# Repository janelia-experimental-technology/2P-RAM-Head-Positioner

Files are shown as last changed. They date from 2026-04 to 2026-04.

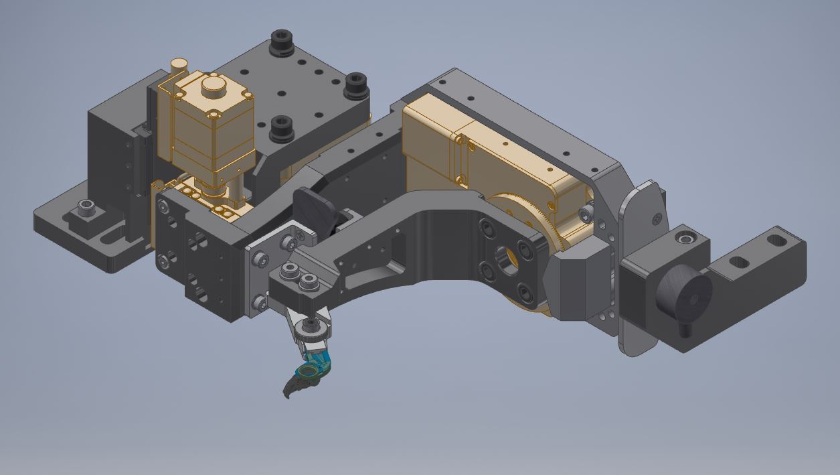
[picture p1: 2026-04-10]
V1-Original Design/MBS POSITIONER SCREENSHOT.JPG

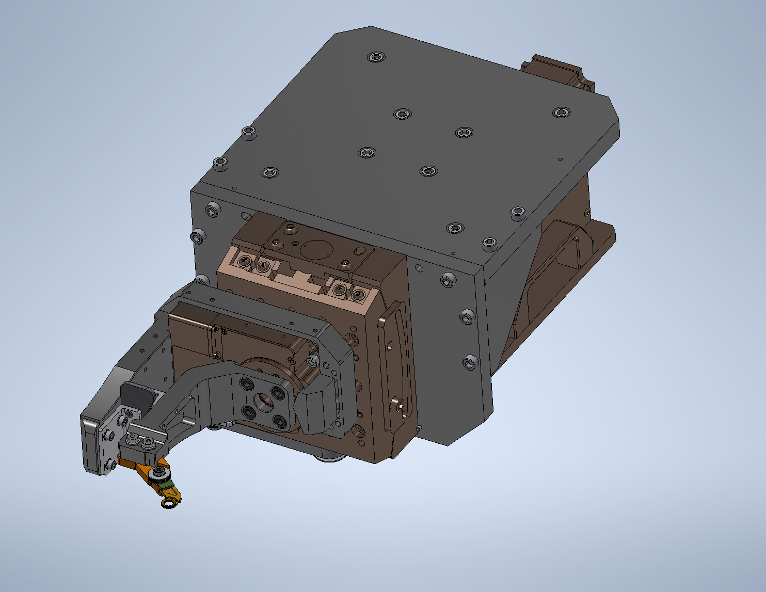
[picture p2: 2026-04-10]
V2-Revised Design/2P-RAM HEAD POSITIONER V2.png

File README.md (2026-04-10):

### Head Positioner for 2P-RAM 2P-RAM Imaging

The motorized head positioner/goniometer allows the user to position the headbar in an automated, repeatable location underneath the microscope. It was designed to work with the 2P-RAM microscope objective and headbars, and leaves the sides of the mouse’s head unobstructed so that camera lenses or other equipment may be mounted close to the head. The device provides automated rotation of a head-fixed rodent specimen about the anterior-posterior and medio-lateral axes for imaging or other purposes. The rotation center of the device is the center of the headbar window opening. The device also provides automated Z translation and is designed to be compatible with behavioral setups such as the large spherical and other treadmills. There are two designs contained herein. The first is designed using stages from Zaber only and is included for reference. The second design which we recommend uses a rotation stages from Zaber and two other stages from Optics Focus which provide a more stable platform. 

Specifications:

&#x20;   Rotation range around Anterior-Posterior axis : +/-20 degrees

&#x20;   Rotation range around Medio-Lateral axis : +/- 8 degrees

&#x20;   Z travel: +/- 10 mm

Opportunity: Free to make for Non-Profit Research by downloading the design here. See included hardware license.

Rights and designs available for Commercial License. Janelia makes no endorsements or guarantees of licensee products.

For inquiries, please contact innovation@janelia.hhmi.org and reference this repository.

To cite the designs, please use DOI: https://doi.org/10.25378/janelia.31985325

Supercedes FLintbox ID 2018-018.

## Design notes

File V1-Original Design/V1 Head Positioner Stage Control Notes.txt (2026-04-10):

The Motorized stages in the V1 Head Positioner design are controlled by Zaber stepper motor controllers. These in combination with the Zaber Console software allow easy control and positioning of the three axes. The V1 positioner has three Zaber stages which connect directly to the Zaber Controllers. The original Zaber A-MCA controllers are now obsolete and we recommend the X-MCC 3 axis controller as a suitable replacement.

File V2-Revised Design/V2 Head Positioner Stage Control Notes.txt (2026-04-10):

The Motorized stages in the V2 Head Positioner design are controlled by Zaber stepper motor controllers. These in combination with the Zaber Console software allow easy control and positioning of the three axes. The V2 positioner has one Zaber rotary stage and two stepper motor driven stages from Optics Focus ( the goniometer and Z stage). Adapter cables were made connecting the DB9 connectors on the Optics Focus stages to the Zaber Controllers. Pinout diagrams can be found on the Optics Focus and Zaber websites for reference. The original Zaber A-MCA controllers are now obsolete and we recommend the X-MCC 3 axis controller as a suitable replacement.

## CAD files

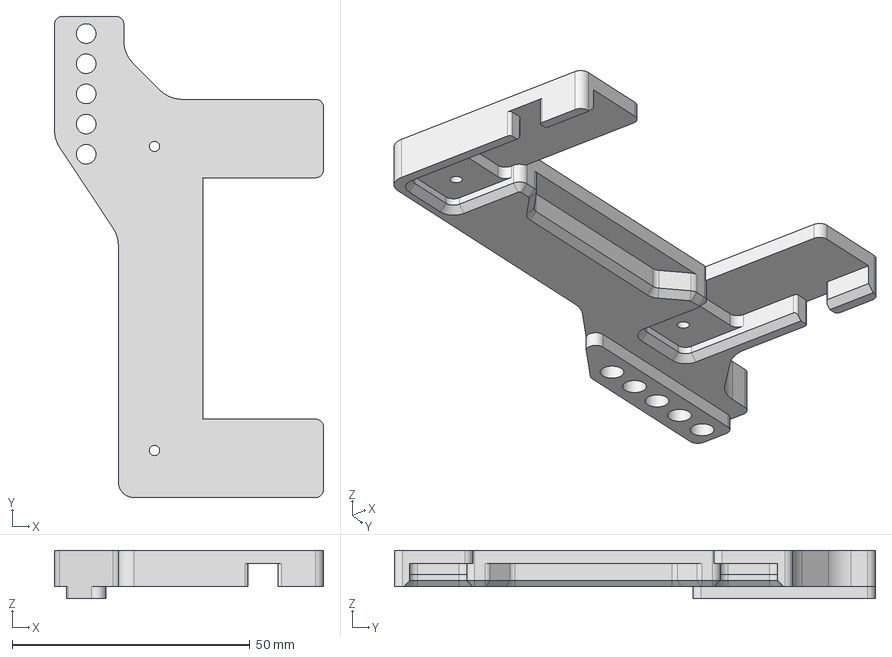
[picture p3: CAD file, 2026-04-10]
V1-Original Design/Part Drawings and Models/MBS INLINE SLIDE HOLDER Rev - J005316.stp
56.6 x 101.3 x 10.2 mm

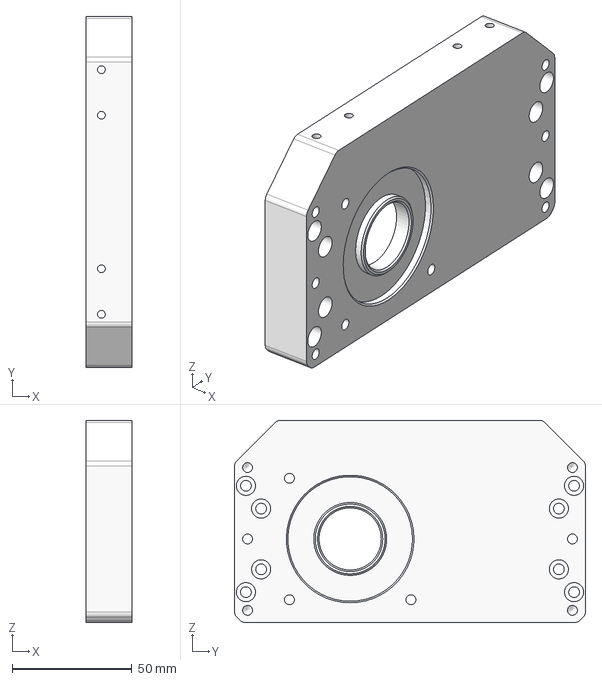
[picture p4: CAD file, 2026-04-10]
V1-Original Design/Part Drawings and Models/J003054 MBS OUTER POSARM L Rev -.stp
19.1 x 146.7 x 84.5 mm

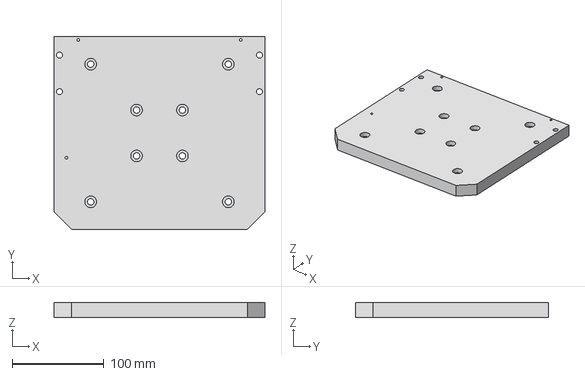
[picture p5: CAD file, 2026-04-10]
V2-Revised Design/Part Models and Drawings/J008085 BBP Z STAGE MTG PLATE Rev - .stp
230.0 x 210.0 x 15.9 mm

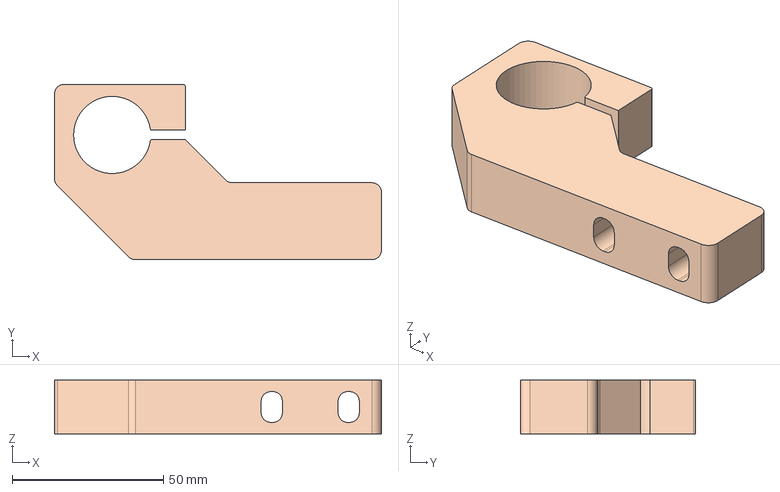
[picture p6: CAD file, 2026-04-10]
V1-Original Design/Part Drawings and Models/J005363 MBS MAGNET MOUNT Rev -.stp
107.9 x 57.9 x 17.8 mm

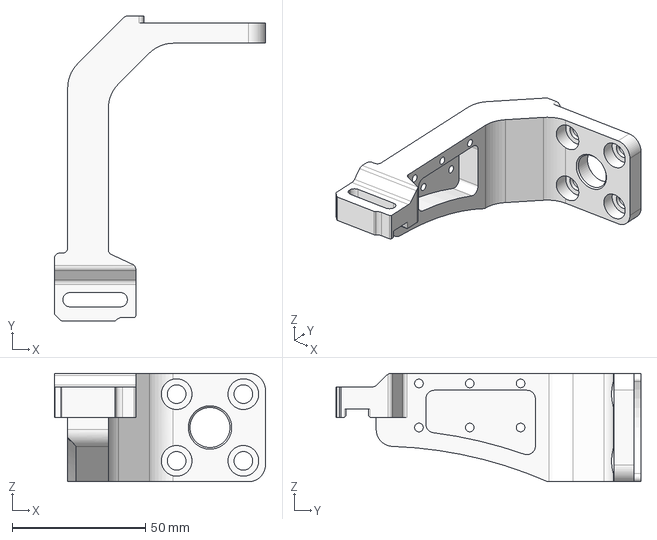
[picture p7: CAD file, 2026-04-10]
V2-Revised Design/Part Models and Drawings/J003057 MBS INNER POSARM Rev -.stp
79.1 x 114.2 x 40.6 mm

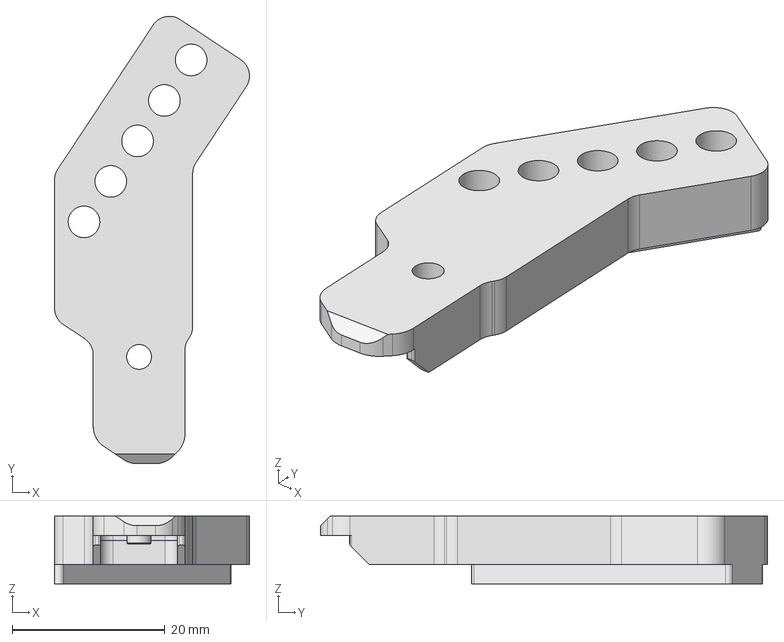
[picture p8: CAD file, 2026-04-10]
V1-Original Design/Part Drawings and Models/J005048 MBS Inline Clamp Arm Rev A.stp
25.5 x 58.5 x 8.89 mm

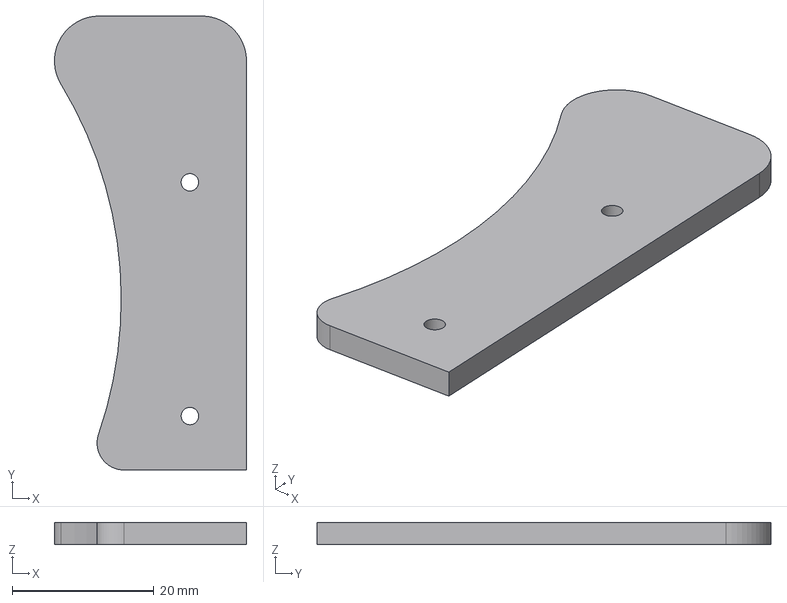
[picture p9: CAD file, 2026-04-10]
V2-Revised Design/Part Models and Drawings/J005357 MBS OUTER STLPART Rev -.stp
27.1 x 64.1 x 3.17 mm

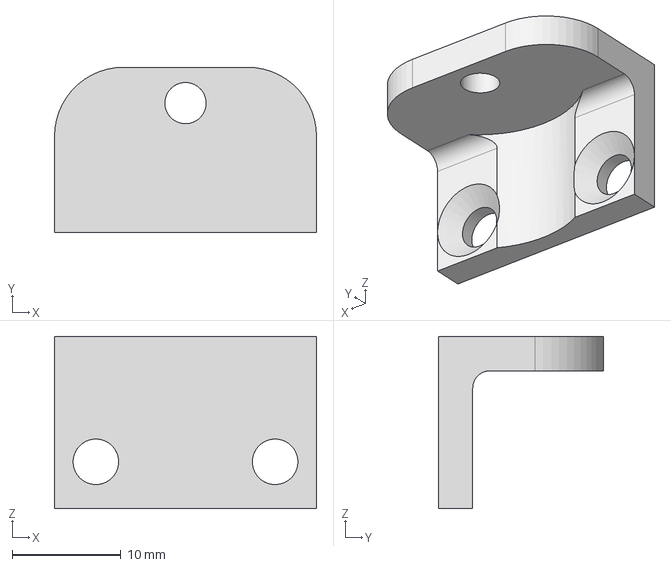
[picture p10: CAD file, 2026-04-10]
V1-Original Design/Part Drawings and Models/J005359 MBS 0_75 EM MNT CLOSER Rev -.stp
24.1 x 15.2 x 15.9 mm

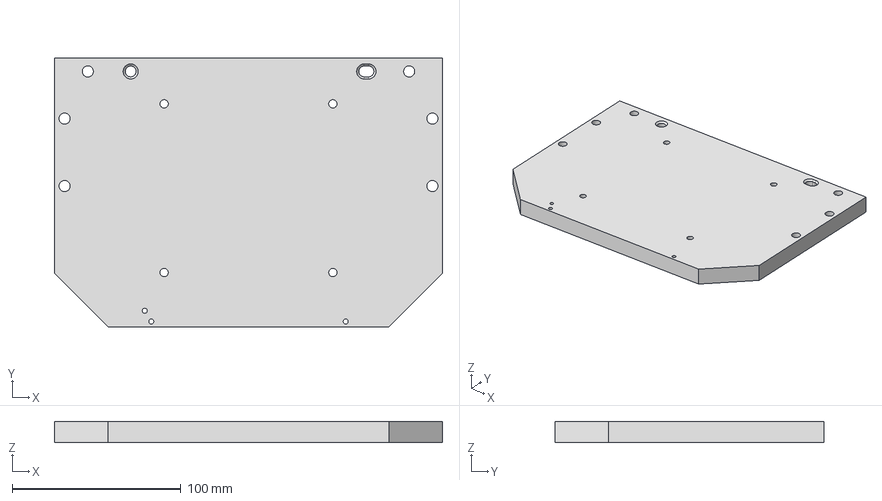
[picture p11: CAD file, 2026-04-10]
V2-Revised Design/Part Models and Drawings/J008086 BBP G STAGE MTG PLATE Rev - .stp
230.0 x 159.4 x 12.7 mm

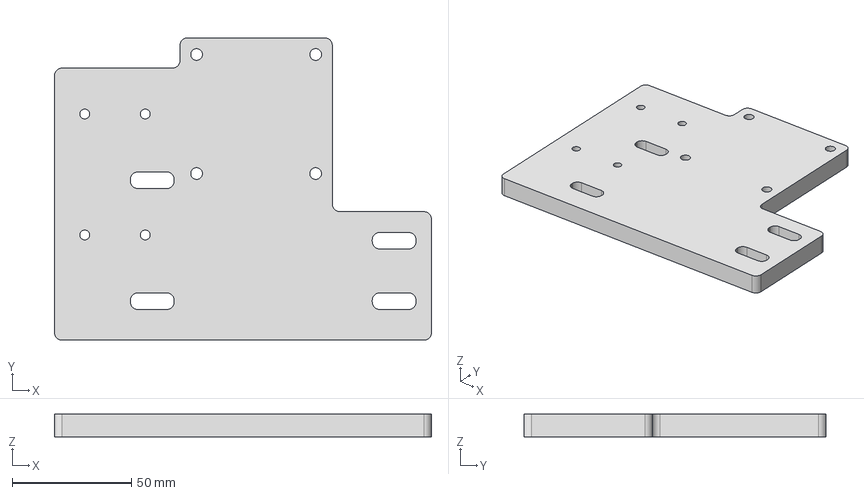
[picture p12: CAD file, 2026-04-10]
V1-Original Design/Part Drawings and Models/J005167 MBS POSITIONER BASE PLATE Rev -.stp
158.4 x 127.0 x 9.53 mm

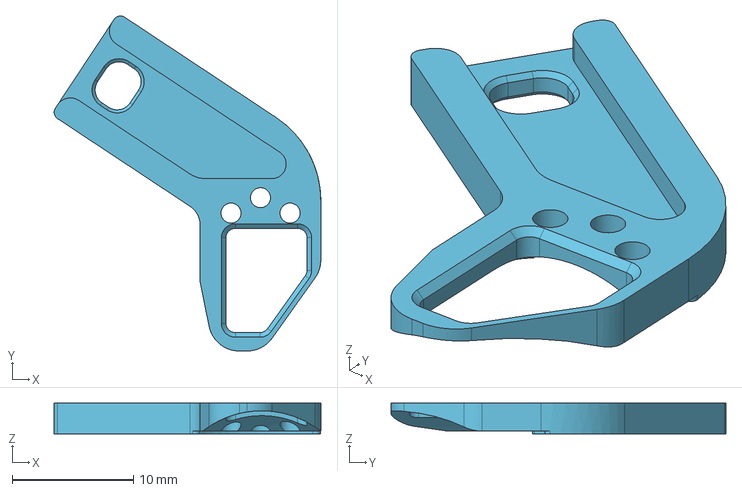
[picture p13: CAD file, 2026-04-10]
V1-Original Design/Part Drawings and Models/J005483 MBS INLINE D TAB Rev A.stp
22.0 x 27.6 x 2.54 mm

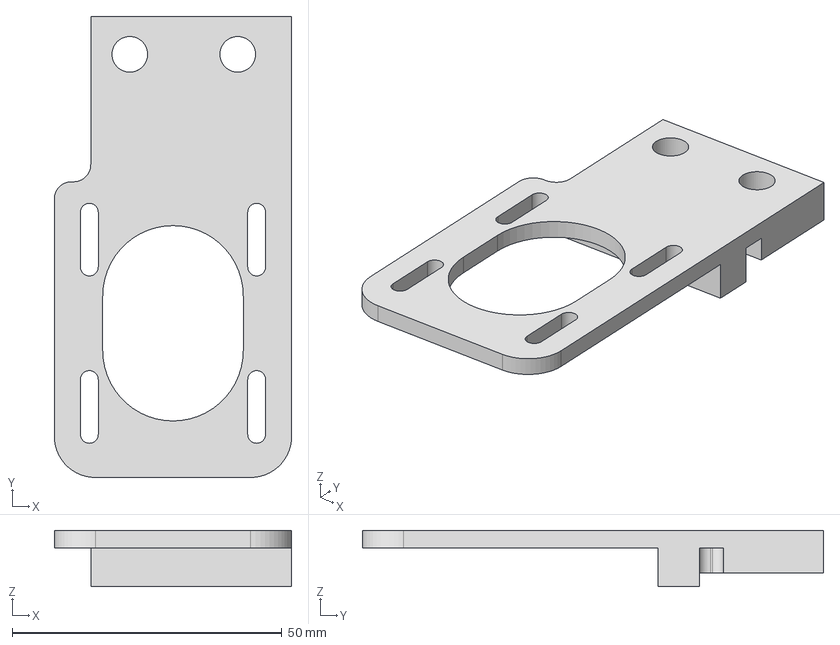
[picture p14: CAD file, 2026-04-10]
V2-Revised Design/Part Models and Drawings/J008087 BBP GONIO MOTOR SHIFT PLATE Rev -.stp
44.0 x 85.4 x 10.4 mm

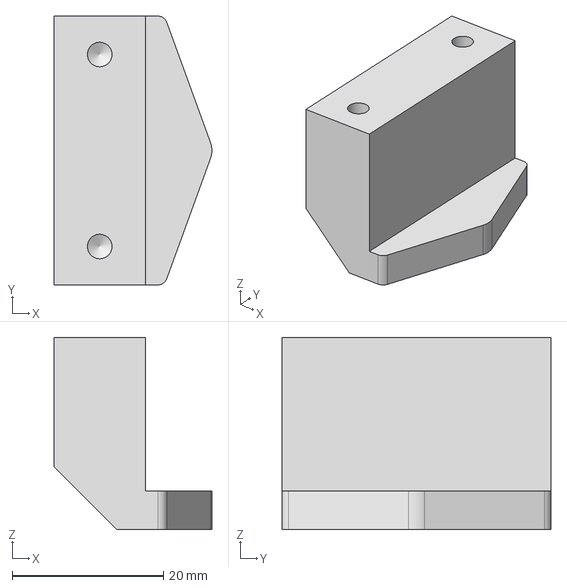
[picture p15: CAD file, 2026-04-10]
V1-Original Design/Part Drawings and Models/J005413 MBS HARD STOP BASE Rev - .stp
20.9 x 35.6 x 25.4 mm

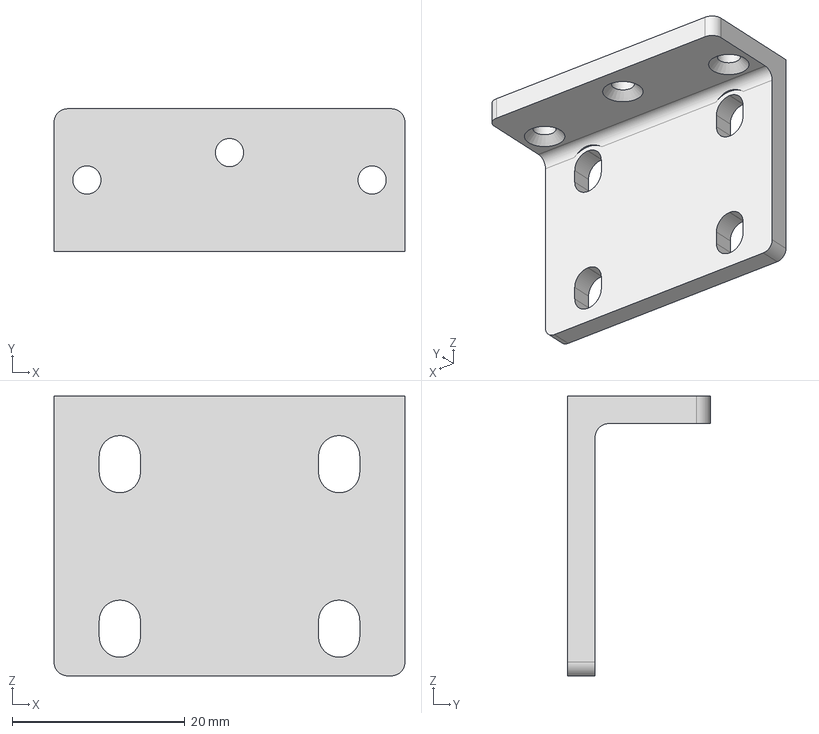
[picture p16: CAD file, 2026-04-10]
V2-Revised Design/Part Models and Drawings/J005358 MBS OUTER PA GUIDE ANGLE Rev -.stp
40.6 x 16.5 x 32.4 mm

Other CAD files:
V1-Original Design/Part Drawings and Models/J005362 MBS LOCK MTG BRACKET Rev -.stp
V2-Revised Design/Part Models and Drawings/J008101 BBP OUTER POSARM L Rev -.stp
V1-Original Design/Inventor Pack and Go/10572.ipt
V1-Original Design/Inventor Pack and Go/5698K113.ipt
V1-Original Design/Inventor Pack and Go/90145A512.ipt
V1-Original Design/Inventor Pack and Go/90666A124.ipt
V1-Original Design/Inventor Pack and Go/90945A726.ipt
V1-Original Design/Inventor Pack and Go/90965A130.ipt
V1-Original Design/Inventor Pack and Go/90965A170.ipt
V1-Original Design/Inventor Pack and Go/91111A118.ipt
V1-Original Design/Inventor Pack and Go/91290A073.ipt
V1-Original Design/Inventor Pack and Go/91292A112.ipt
V1-Original Design/Inventor Pack and Go/91292A116.ipt
V1-Original Design/Inventor Pack and Go/91292A121.ipt
V1-Original Design/Inventor Pack and Go/91292A126.ipt
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

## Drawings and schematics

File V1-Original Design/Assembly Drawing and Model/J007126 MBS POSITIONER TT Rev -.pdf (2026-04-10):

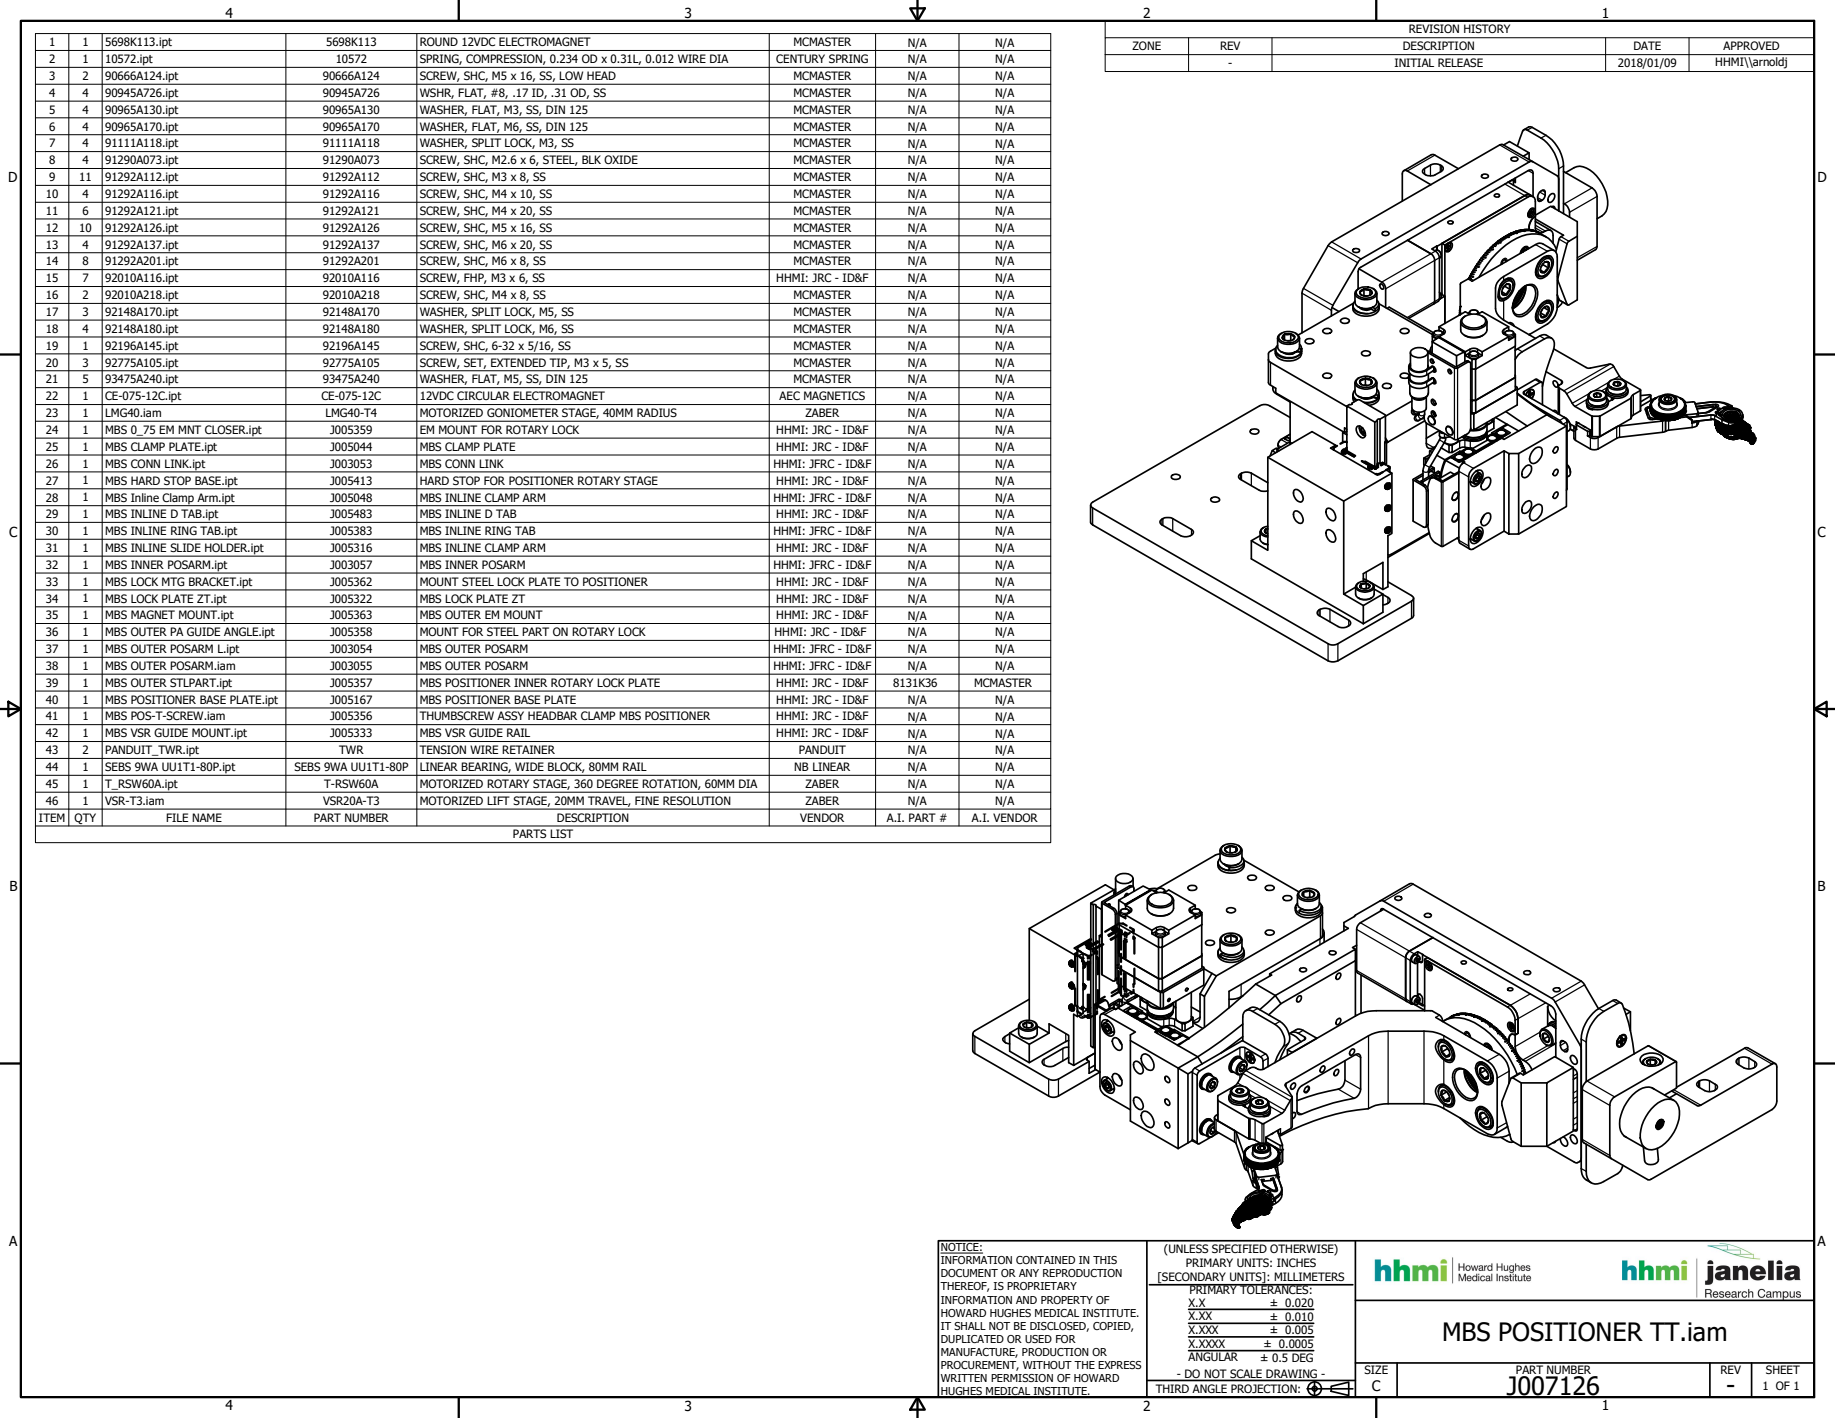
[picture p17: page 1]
5698K113.ipt; ROUND 12VDC ELECTROMAGNET; MCMASTER; 10572.ipt; SPRING, COMPRESSION, 0.234 OD x 0.31L, 0.012 WIRE DIA; CENTURY SPRING; 90666A124.ipt; SCREW, SHC, M5 x 16, SS, LOW HEAD; 90945A726.ipt; WSHR, FLAT, #8, .17 ID, .31 OD, SS; 90965A130.ipt; WASHER, FLAT, M3, SS, DIN 125; 90965A170.ipt; WASHER, FLAT, M6, SS, DIN 125; 91111A118.ipt; WASHER, SPLIT LOCK, M3, SS; 91290A073.ipt; SCREW, SHC, M2.6 x 6, STEEL, BLK OXIDE; 11 91292A112.ipt; SCREW, SHC, M3 x 8, SS; 91292A116.ipt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

NOTICE:
INFORMATION CONTAINED IN THIS
DOCUMENT OR ANY REPRODUCTION
THEREOF, IS PROPRIETARY
INFORMATION AND PROPERTY OF
HOWARD HUGHES MEDICAL INSTITUTE.
IT SHALL NOT BE DISCLOSED, COPIED,
DUPLICATED OR USED FOR
MANUFACTURE, PRODUCTION OR
PROCUREMENT, WITHOUT THE EXPRESS
WRITTEN PERMISSION OF HOWARD
HUGHES MEDICAL INSTITUTE.

(UNLESS SPECIFIED OTHERWISE)
PRIMARY UNITS: INCHES
[SECONDARY UNITS]: MILLIMETERS
PRIMARY TOLERANCES:
X.XXX
X.XXXX
ANGULAR
- DO NOT SCALE DRAWING -

MBS POSITIONER TT.iam

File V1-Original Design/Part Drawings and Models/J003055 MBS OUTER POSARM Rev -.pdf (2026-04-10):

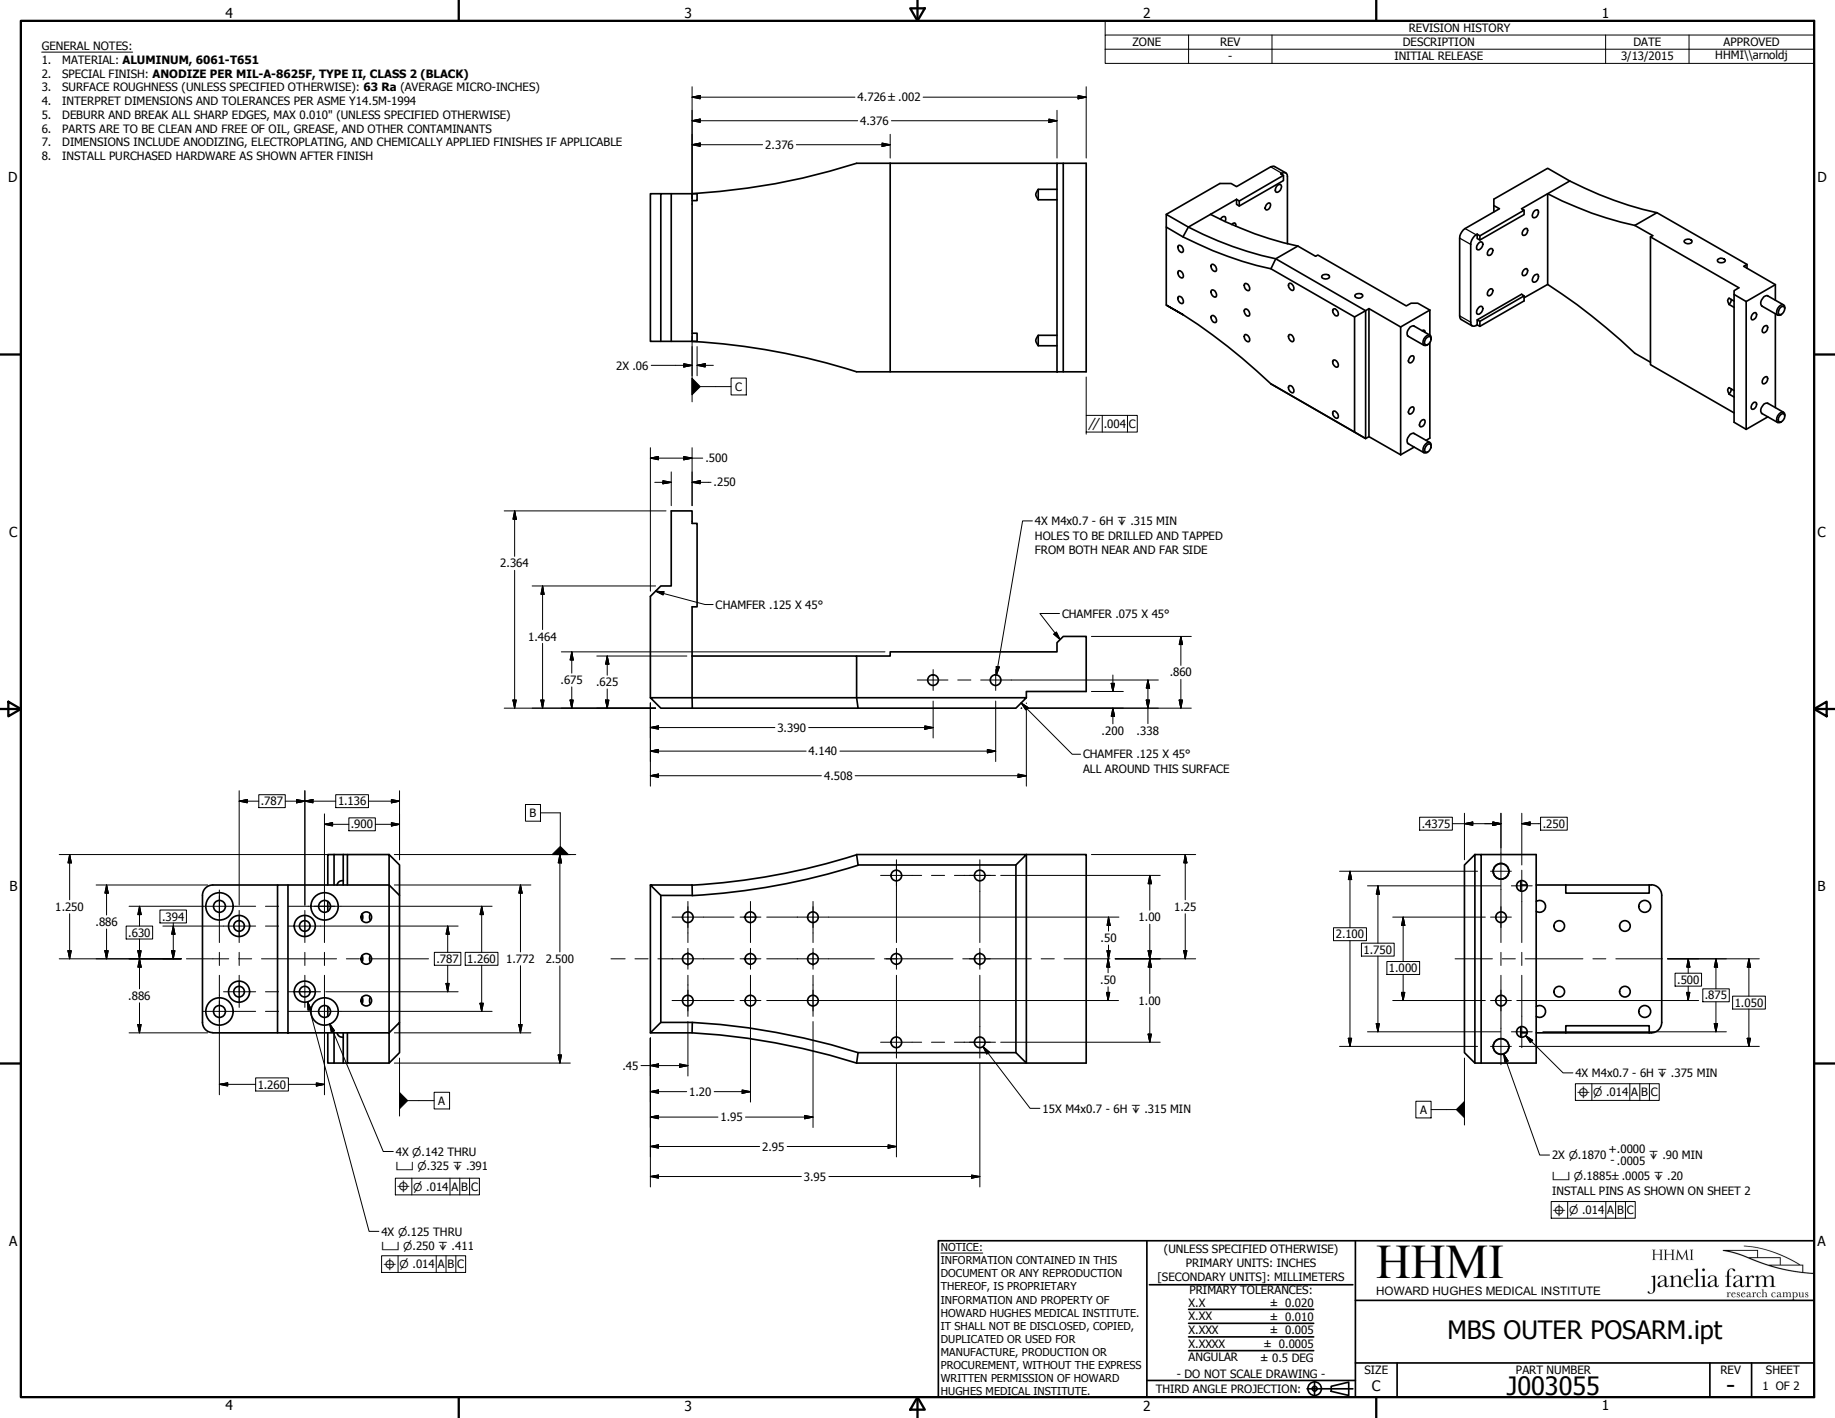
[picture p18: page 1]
PART NUMBER; HHMI; SIZE; REV; SHEET; 1 OF 2 THIRD ANGLE PROJECTION:; ± 0.020 ± 0.010 ± 0.005 ± 0.0005 ± 0.5 DEG; REVISION HISTORY; ZONE; DESCRIPTION; DATE; APPROVED; INITIAL RELEASE; HHMI\\arnoldj; CHAMFER .125 X 45°; 15X M4x0.7 - 6H Z .315 MIN; +.0000 Z .90 MIN; 4X M4x0.7 - 6H Z .375 MIN; CHAMFER .075 X 45°; 4X P.142 THRU X P.325 Z .391; 4X P.125 THRU X P.250 Z .411

GENERAL NOTES:
1. MATERIAL: ALUMINUM, 6061-T651
2. SPECIAL FINISH: ANODIZE PER MIL-A-8625F, TYPE II, CLASS 2 (BLACK)
3. SURFACE ROUGHNESS (UNLESS SPECIFIED OTHERWISE): 63 Ra (AVERAGE MICRO-INCHES)
4. INTERPRET DIMENSIONS AND TOLERANCES PER ASME Y14.5M-1994
5. DEBURR AND BREAK ALL SHARP EDGES, MAX 0.010" (UNLESS SPECIFIED OTHERWISE)
6. PARTS ARE TO BE CLEAN AND FREE OF OIL, GREASE, AND OTHER CONTAMINANTS
7. DIMENSIONS INCLUDE ANODIZING, ELECTROPLATING, AND CHEMICALLY APPLIED FINISHES IF APPLICABLE
8. INSTALL PURCHASED HARDWARE AS SHOWN AFTER FINISH

4X M4x0.7 - 6H Z .315 MIN
HOLES TO BE DRILLED AND TAPPED
FROM BOTH NEAR AND FAR SIDE

CHAMFER .125 X 45°
ALL AROUND THIS SURFACE

INSTALL PINS AS SHOWN ON SHEET 2

NOTICE:
INFORMATION CONTAINED IN THIS
DOCUMENT OR ANY REPRODUCTION
THEREOF, IS PROPRIETARY
INFORMATION AND PROPERTY OF
HOWARD HUGHES MEDICAL INSTITUTE.
IT SHALL NOT BE DISCLOSED, COPIED,
DUPLICATED OR USED FOR
MANUFACTURE, PRODUCTION OR
PROCUREMENT, WITHOUT THE EXPRESS
WRITTEN PERMISSION OF HOWARD
HUGHES MEDICAL INSTITUTE.

(UNLESS SPECIFIED OTHERWISE)
PRIMARY UNITS: INCHES
[SECONDARY UNITS]: MILLIMETERS
PRIMARY TOLERANCES:
X.XXX
X.XXXX
ANGULAR
- DO NOT SCALE DRAWING -

HOWARD HUGHES MEDICAL INSTITUTE
MBS OUTER POSARM.ipt

# SECTION E-E

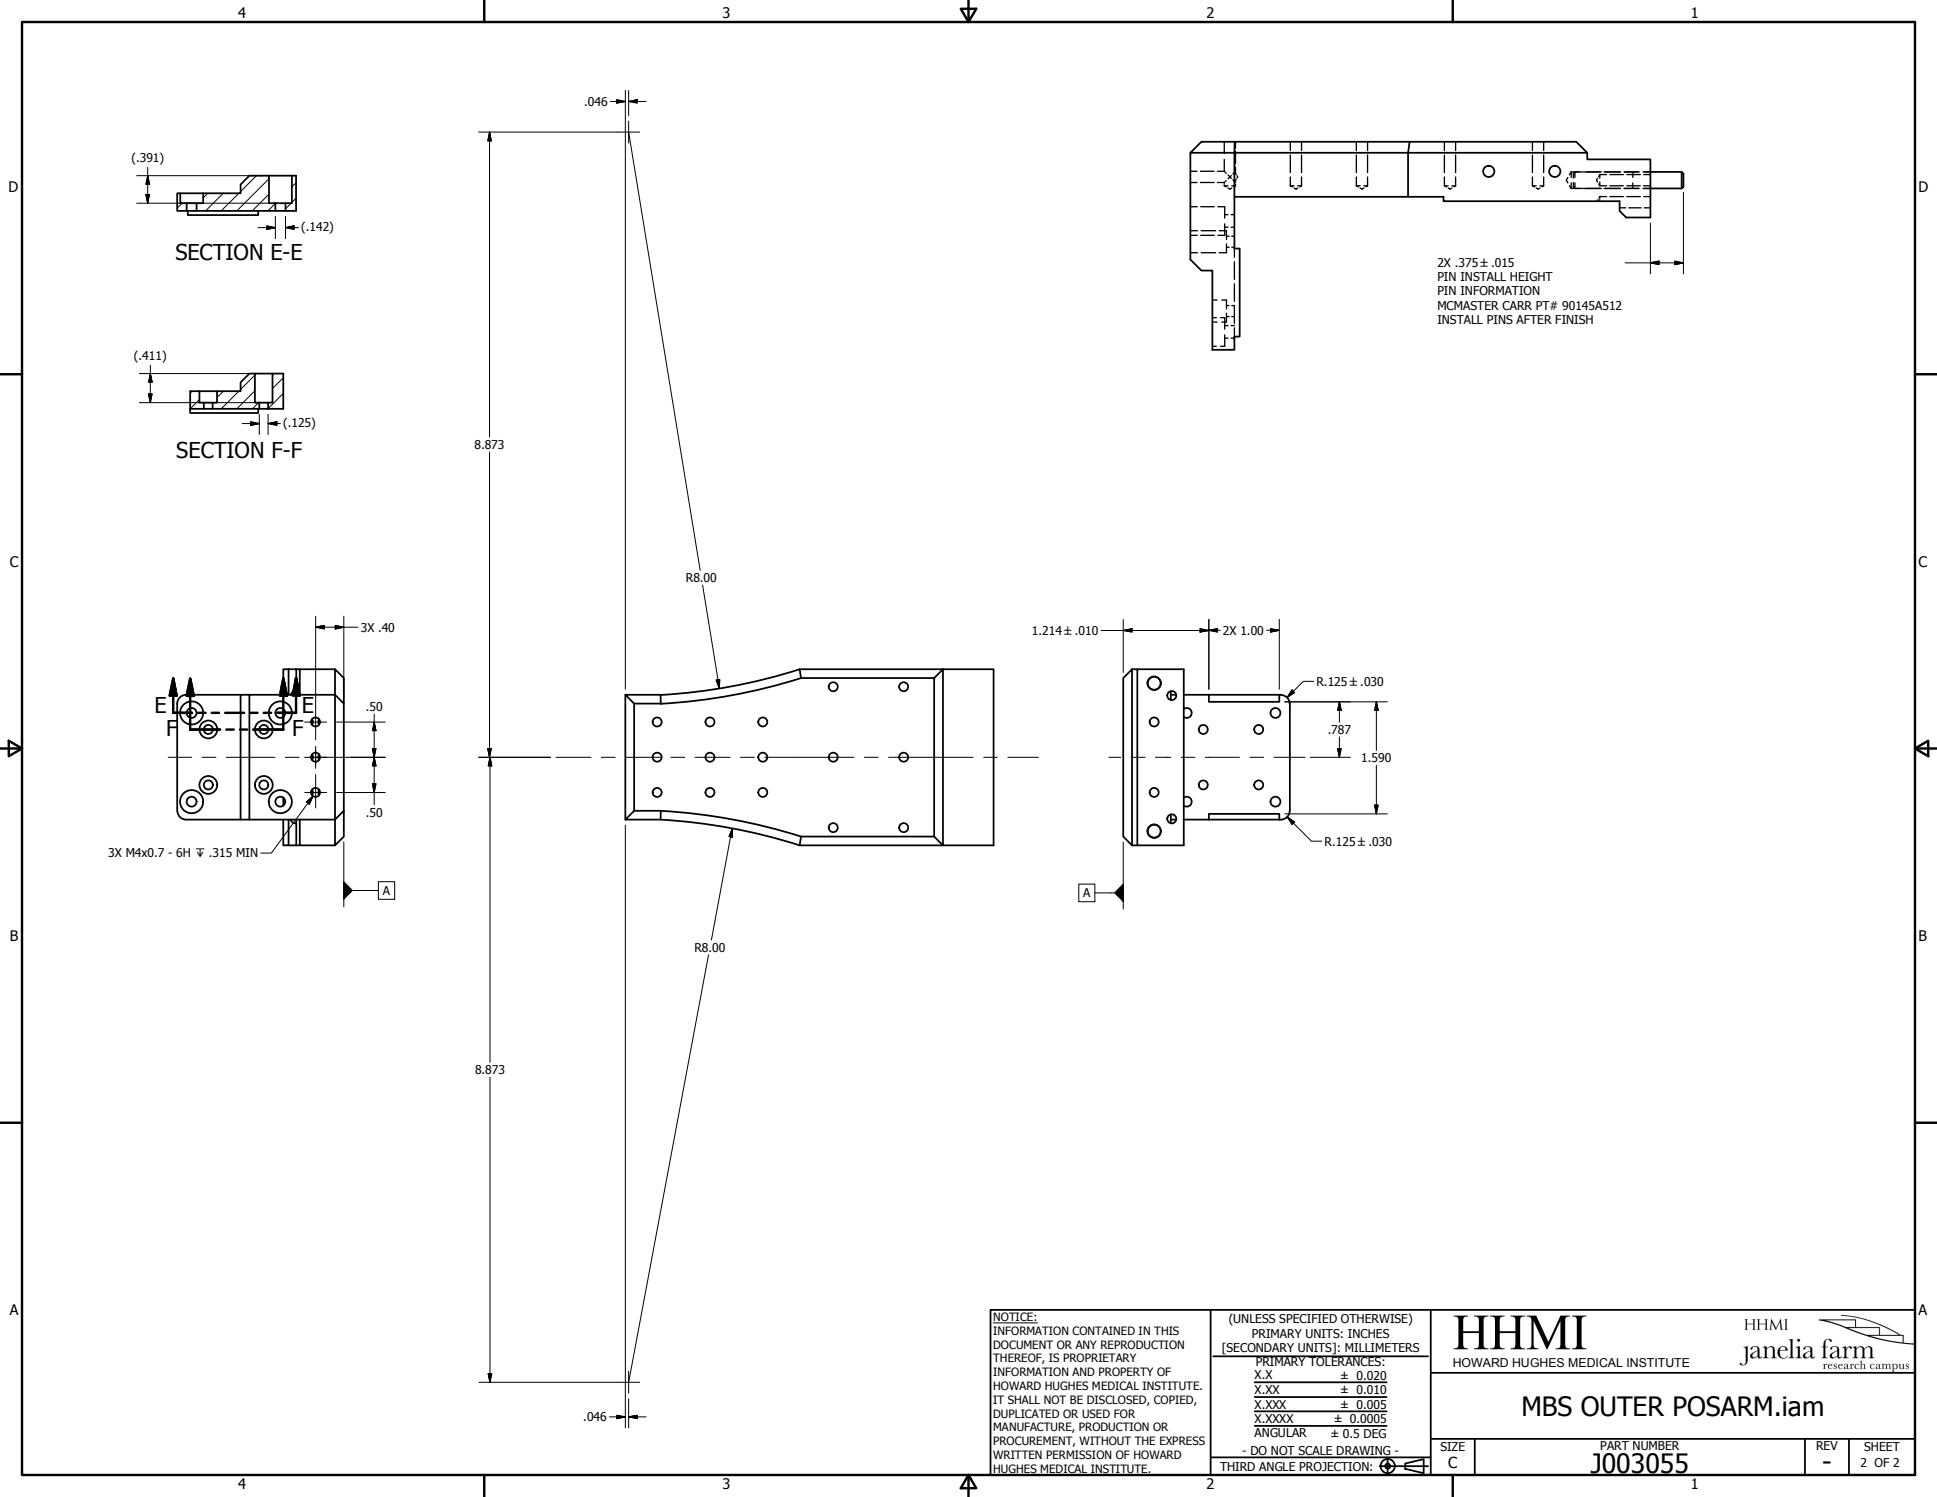
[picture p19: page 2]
SECTION F-F; PART NUMBER; HHMI; SIZE; REV; SHEET; 2 OF 2 THIRD ANGLE PROJECTION:; ± 0.020 ± 0.010 ± 0.005 ± 0.0005 ± 0.5 DEG; 3X M4x0.7 - 6H Z .315 MIN

PIN INSTALL HEIGHT
PIN INFORMATION
MCMASTER CARR PT# 90145A512
INSTALL PINS AFTER FINISH

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

HOWARD HUGHES MEDICAL INSTITUTE
MBS OUTER POSARM.iam

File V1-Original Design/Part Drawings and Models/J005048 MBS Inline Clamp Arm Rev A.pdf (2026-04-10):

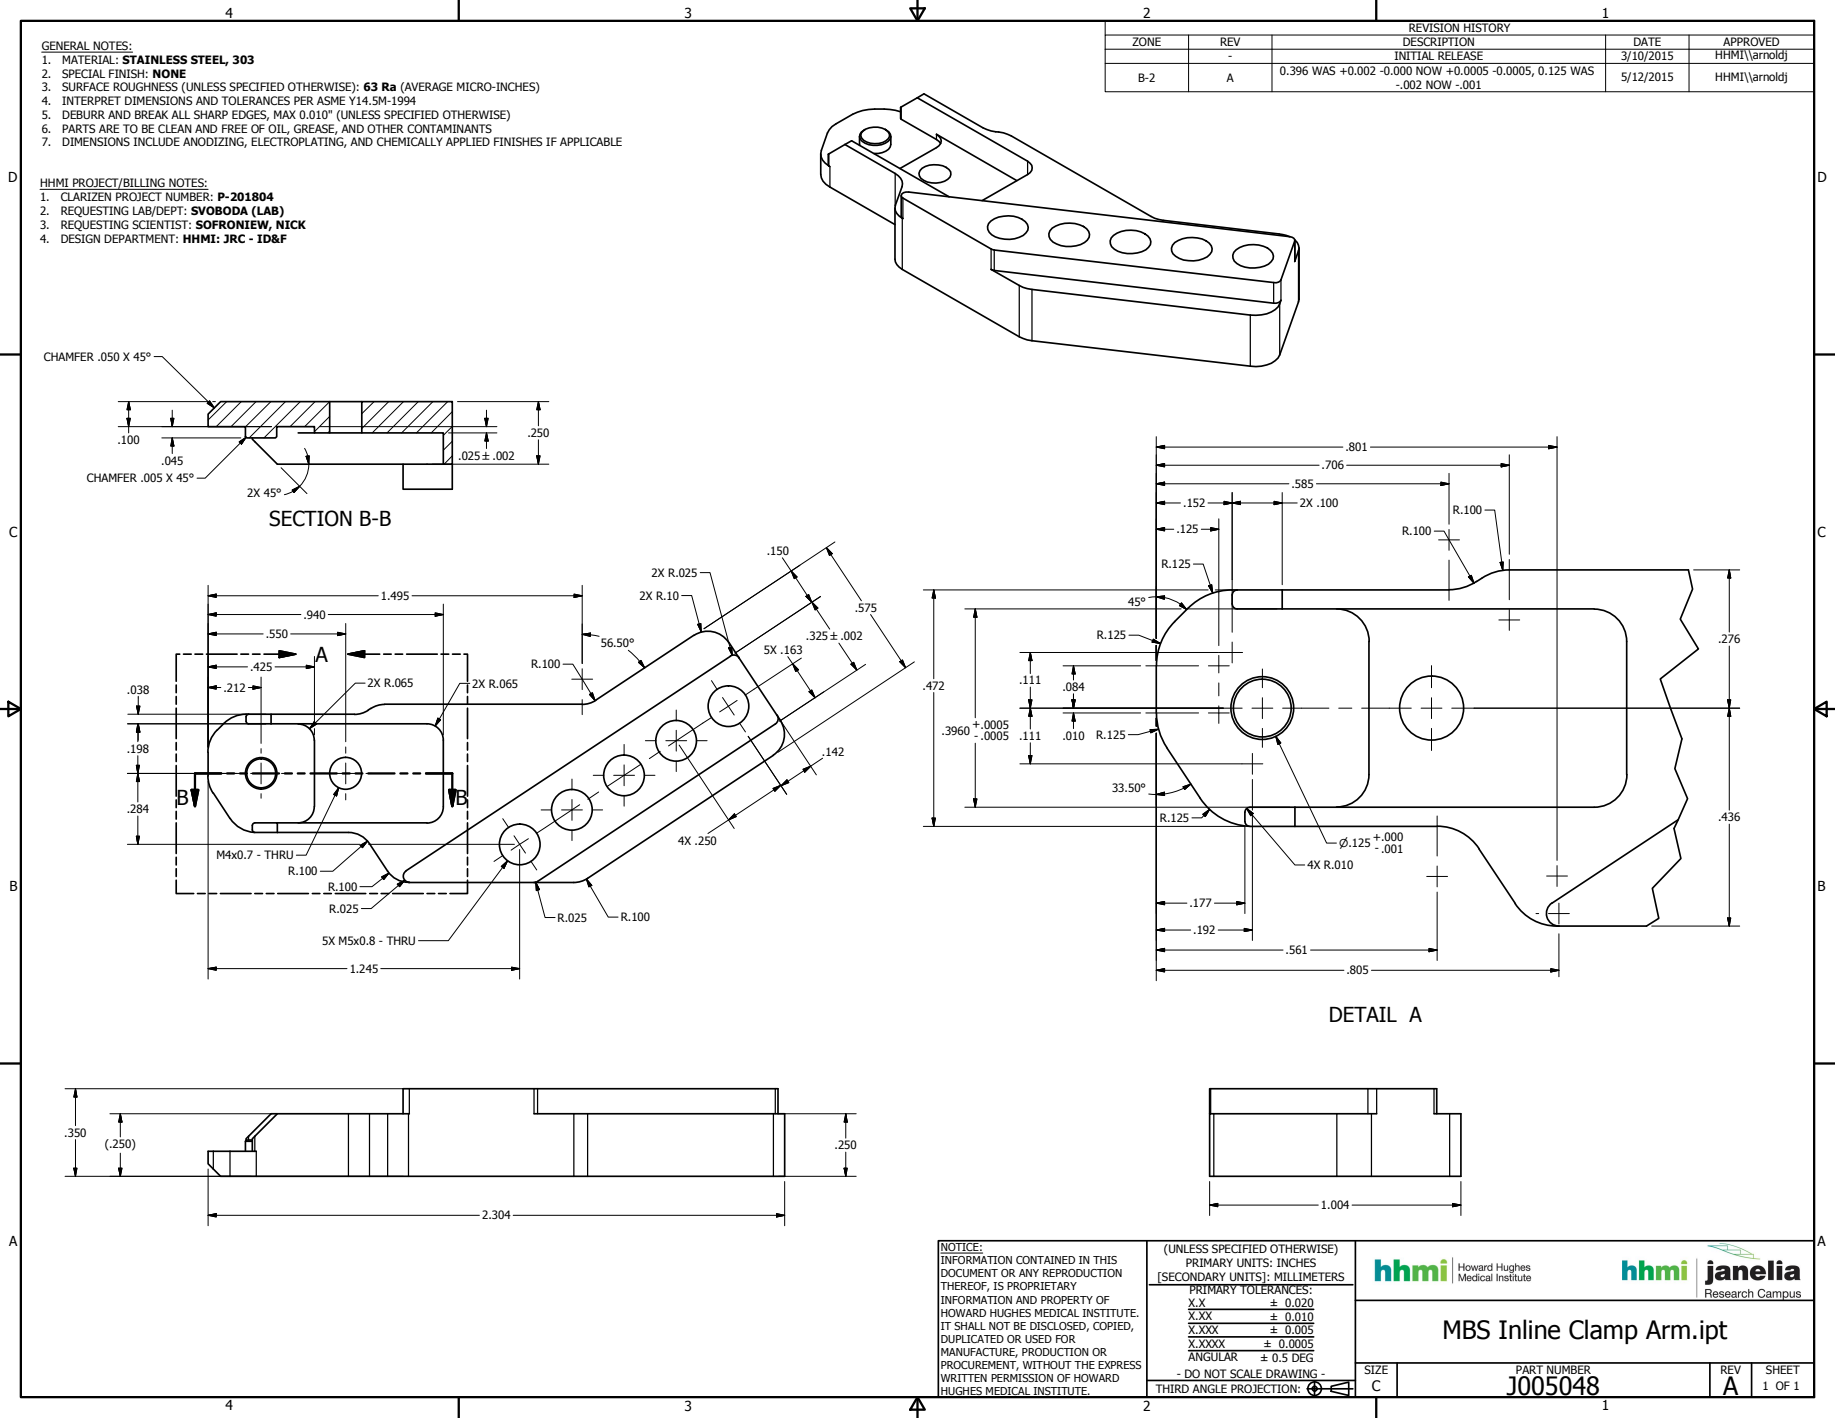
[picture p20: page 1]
DETAIL A; SECTION B-B; PART NUMBER; SIZE; REV; SHEET; 1 OF 1 THIRD ANGLE PROJECTION:; ± 0.020 ± 0.010 ± 0.005 ± 0.0005 ± 0.5 DEG; REVISION HISTORY; ZONE; DESCRIPTION; DATE; APPROVED; INITIAL RELEASE; HHMI\\arnoldj; -.002 NOW -.001; CHAMFER .050 X 45°; CHAMFER .005 X 45°; M4x0.7 - THRU; 5X M5x0.8 - THRU

GENERAL NOTES:
1. MATERIAL: STAINLESS STEEL, 303
2. SPECIAL FINISH: NONE
3. SURFACE ROUGHNESS (UNLESS SPECIFIED OTHERWISE): 63 Ra (AVERAGE MICRO-INCHES)
4. INTERPRET DIMENSIONS AND TOLERANCES PER ASME Y14.5M-1994
5. DEBURR AND BREAK ALL SHARP EDGES, MAX 0.010" (UNLESS SPECIFIED OTHERWISE)
6. PARTS ARE TO BE CLEAN AND FREE OF OIL, GREASE, AND OTHER CONTAMINANTS
7. DIMENSIONS INCLUDE ANODIZING, ELECTROPLATING, AND CHEMICALLY APPLIED FINISHES IF APPLICABLE

0.396 WAS +0.002 -0.000 NOW +0.0005 -0.0005, 0.125 WAS

HHMI PROJECT/BILLING NOTES:
1. CLARIZEN PROJECT NUMBER: P-201804
2. REQUESTING LAB/DEPT: SVOBODA (LAB)
3. REQUESTING SCIENTIST: SOFRONIEW, NICK
4. DESIGN DEPARTMENT: HHMI: JRC - ID&F

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

MBS Inline Clamp Arm.ipt

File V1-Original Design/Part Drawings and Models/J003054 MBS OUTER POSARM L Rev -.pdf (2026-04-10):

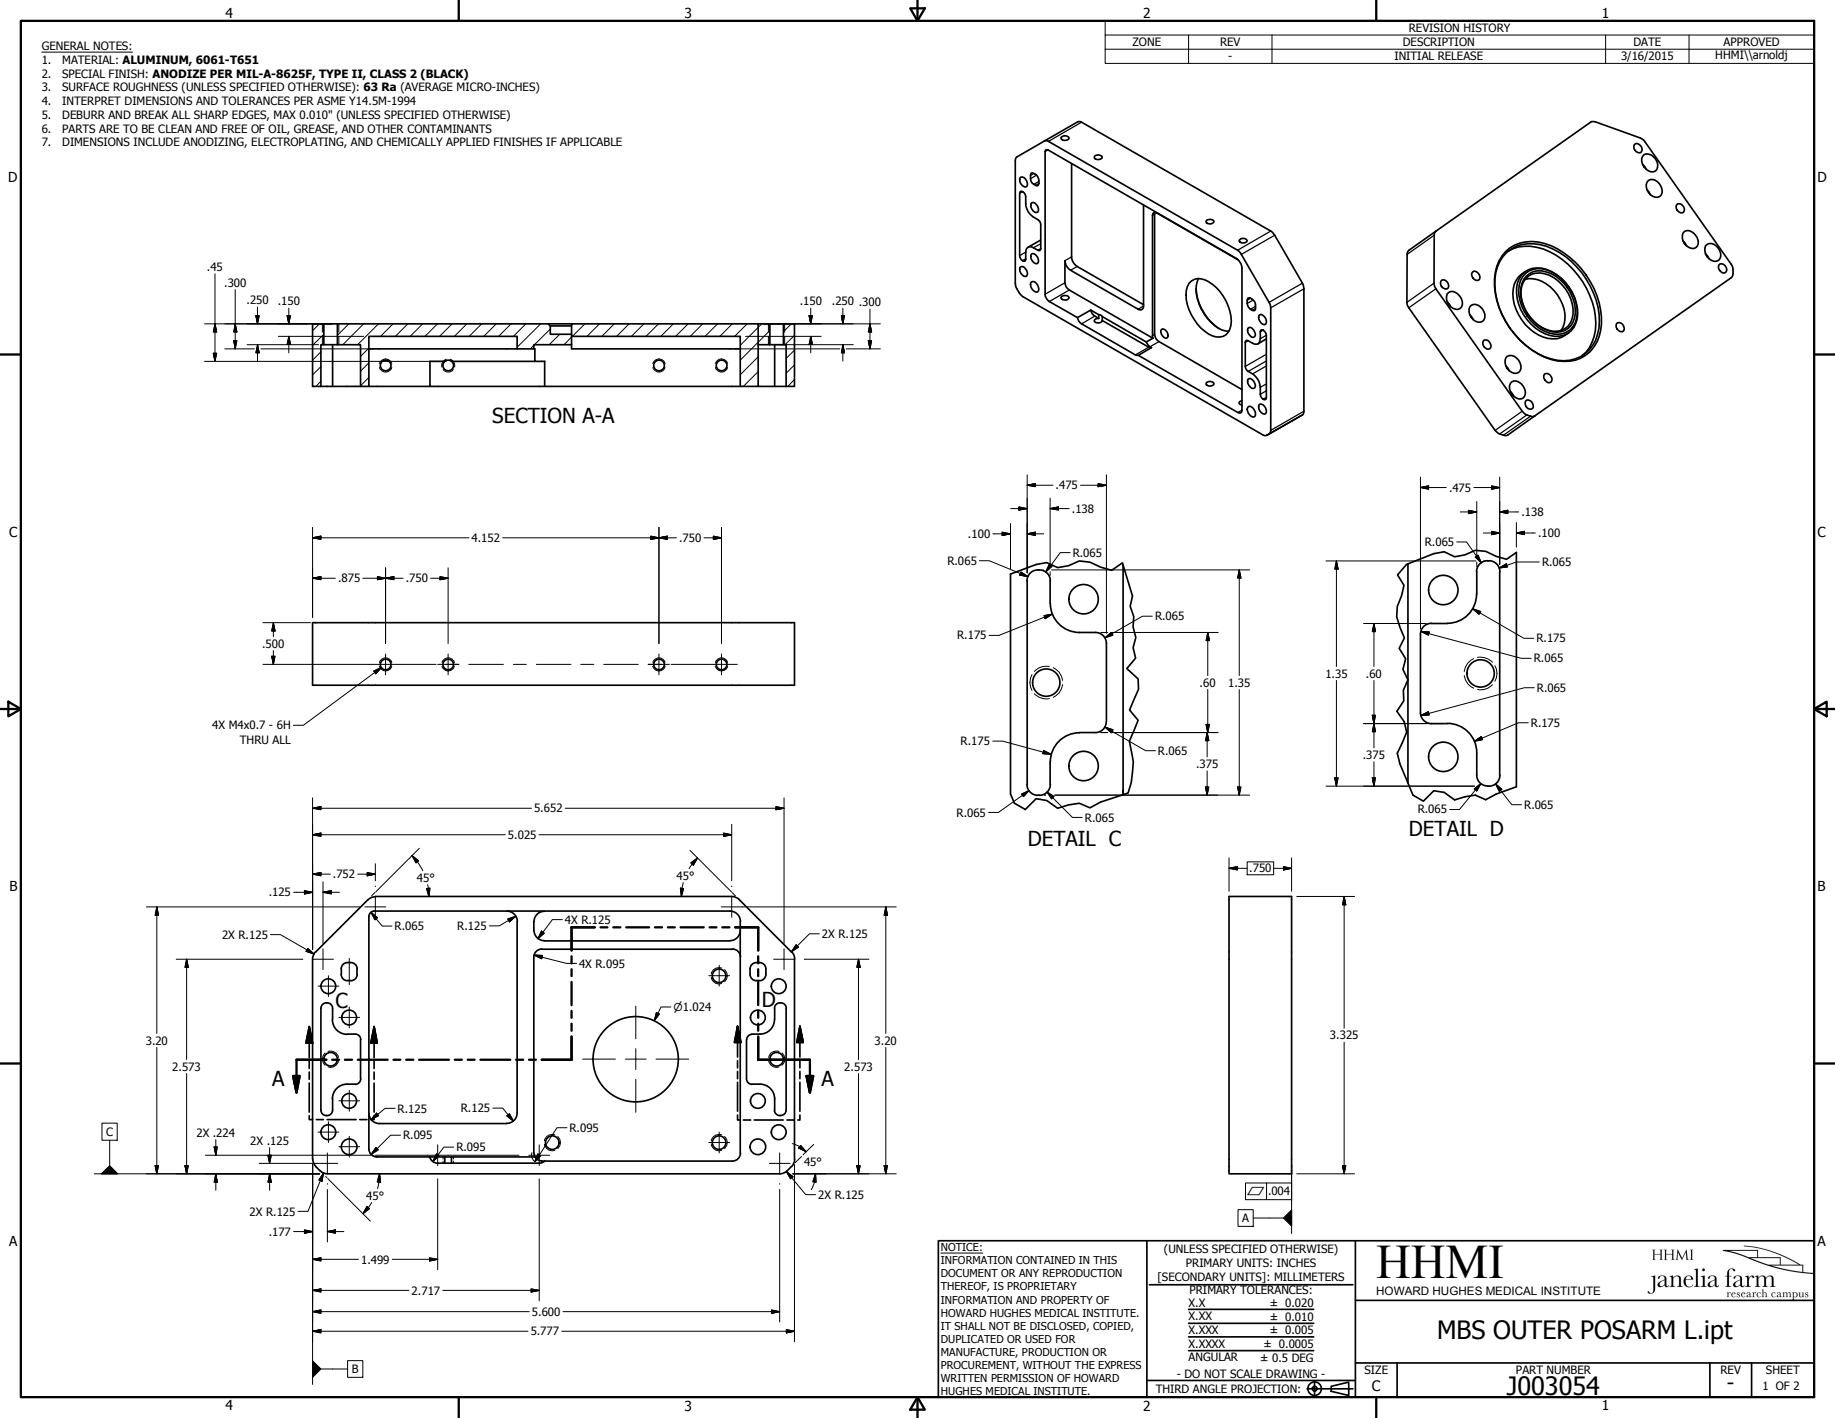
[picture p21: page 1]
SECTION A-A; DETAIL C; DETAIL D; PART NUMBER; HHMI; SIZE; REV; SHEET; 1 OF 2 THIRD ANGLE PROJECTION:; ± 0.020 ± 0.010 ± 0.005 ± 0.0005 ± 0.5 DEG; REVISION HISTORY; ZONE; DESCRIPTION; DATE; APPROVED; INITIAL RELEASE; HHMI\\arnoldj; 4X M4x0.7 - 6H THRU ALL

GENERAL NOTES:
1. MATERIAL: ALUMINUM, 6061-T651
2. SPECIAL FINISH: ANODIZE PER MIL-A-8625F, TYPE II, CLASS 2 (BLACK)
3. SURFACE ROUGHNESS (UNLESS SPECIFIED OTHERWISE): 63 Ra (AVERAGE MICRO-INCHES)
4. INTERPRET DIMENSIONS AND TOLERANCES PER ASME Y14.5M-1994
5. DEBURR AND BREAK ALL SHARP EDGES, MAX 0.010" (UNLESS SPECIFIED OTHERWISE)
6. PARTS ARE TO BE CLEAN AND FREE OF OIL, GREASE, AND OTHER CONTAMINANTS
7. DIMENSIONS INCLUDE ANODIZING, ELECTROPLATING, AND CHEMICALLY APPLIED FINISHES IF APPLICABLE

NOTICE:
INFORMATION CONTAINED IN THIS
DOCUMENT OR ANY REPRODUCTION
THEREOF, IS PROPRIETARY
INFORMATION AND PROPERTY OF
HOWARD HUGHES MEDICAL INSTITUTE.
IT SHALL NOT BE DISCLOSED, COPIED,
DUPLICATED OR USED FOR
MANUFACTURE, PRODUCTION OR
PROCUREMENT, WITHOUT THE EXPRESS
WRITTEN PERMISSION OF HOWARD
HUGHES MEDICAL INSTITUTE.

(UNLESS SPECIFIED OTHERWISE)
PRIMARY UNITS: INCHES
[SECONDARY UNITS]: MILLIMETERS
PRIMARY TOLERANCES:
X.XXX
X.XXXX
ANGULAR
- DO NOT SCALE DRAWING -

HOWARD HUGHES MEDICAL INSTITUTE
MBS OUTER POSARM L.ipt

E

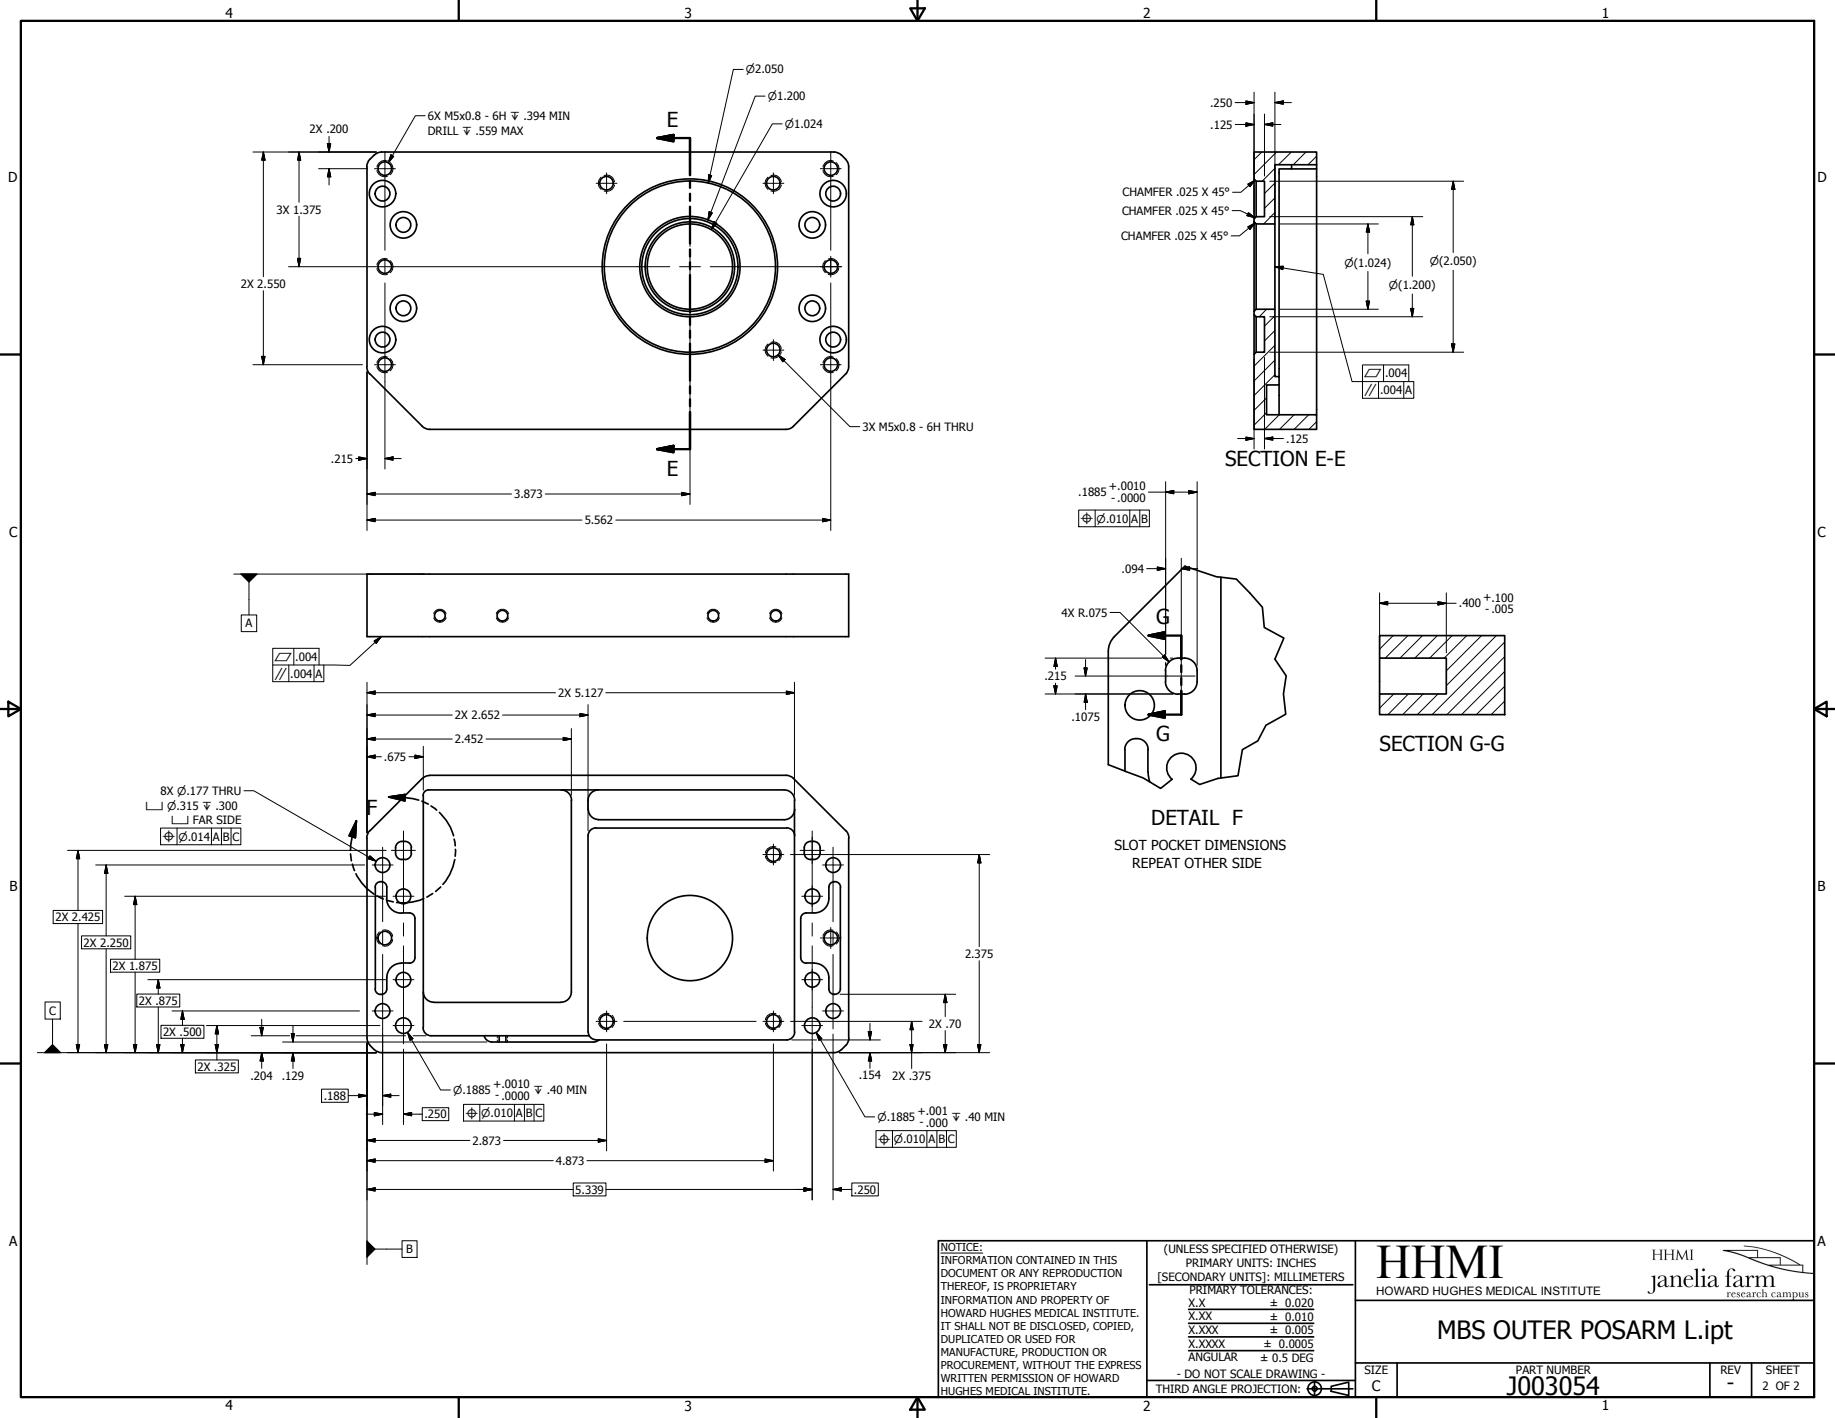
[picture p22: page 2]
SECTION E-E; DETAIL F; SECTION G-G; PART NUMBER; HHMI; SIZE; REV; SHEET; 2 OF 2 THIRD ANGLE PROJECTION:; ± 0.020 ± 0.010 ± 0.005 ± 0.0005 ± 0.5 DEG; CHAMFER .025 X 45°; 6X M5x0.8 - 6H Z .394 MIN DRILL Z .559 MAX; 8X P.177 THRU X P.315 Z .300 X FAR SIDE; +.0010 Z .40 MIN; +.001 Z .40 MIN; 3X M5x0.8 - 6H THRU

SLOT POCKET DIMENSIONS
REPEAT OTHER SIDE

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

HOWARD HUGHES MEDICAL INSTITUTE
MBS OUTER POSARM L.ipt

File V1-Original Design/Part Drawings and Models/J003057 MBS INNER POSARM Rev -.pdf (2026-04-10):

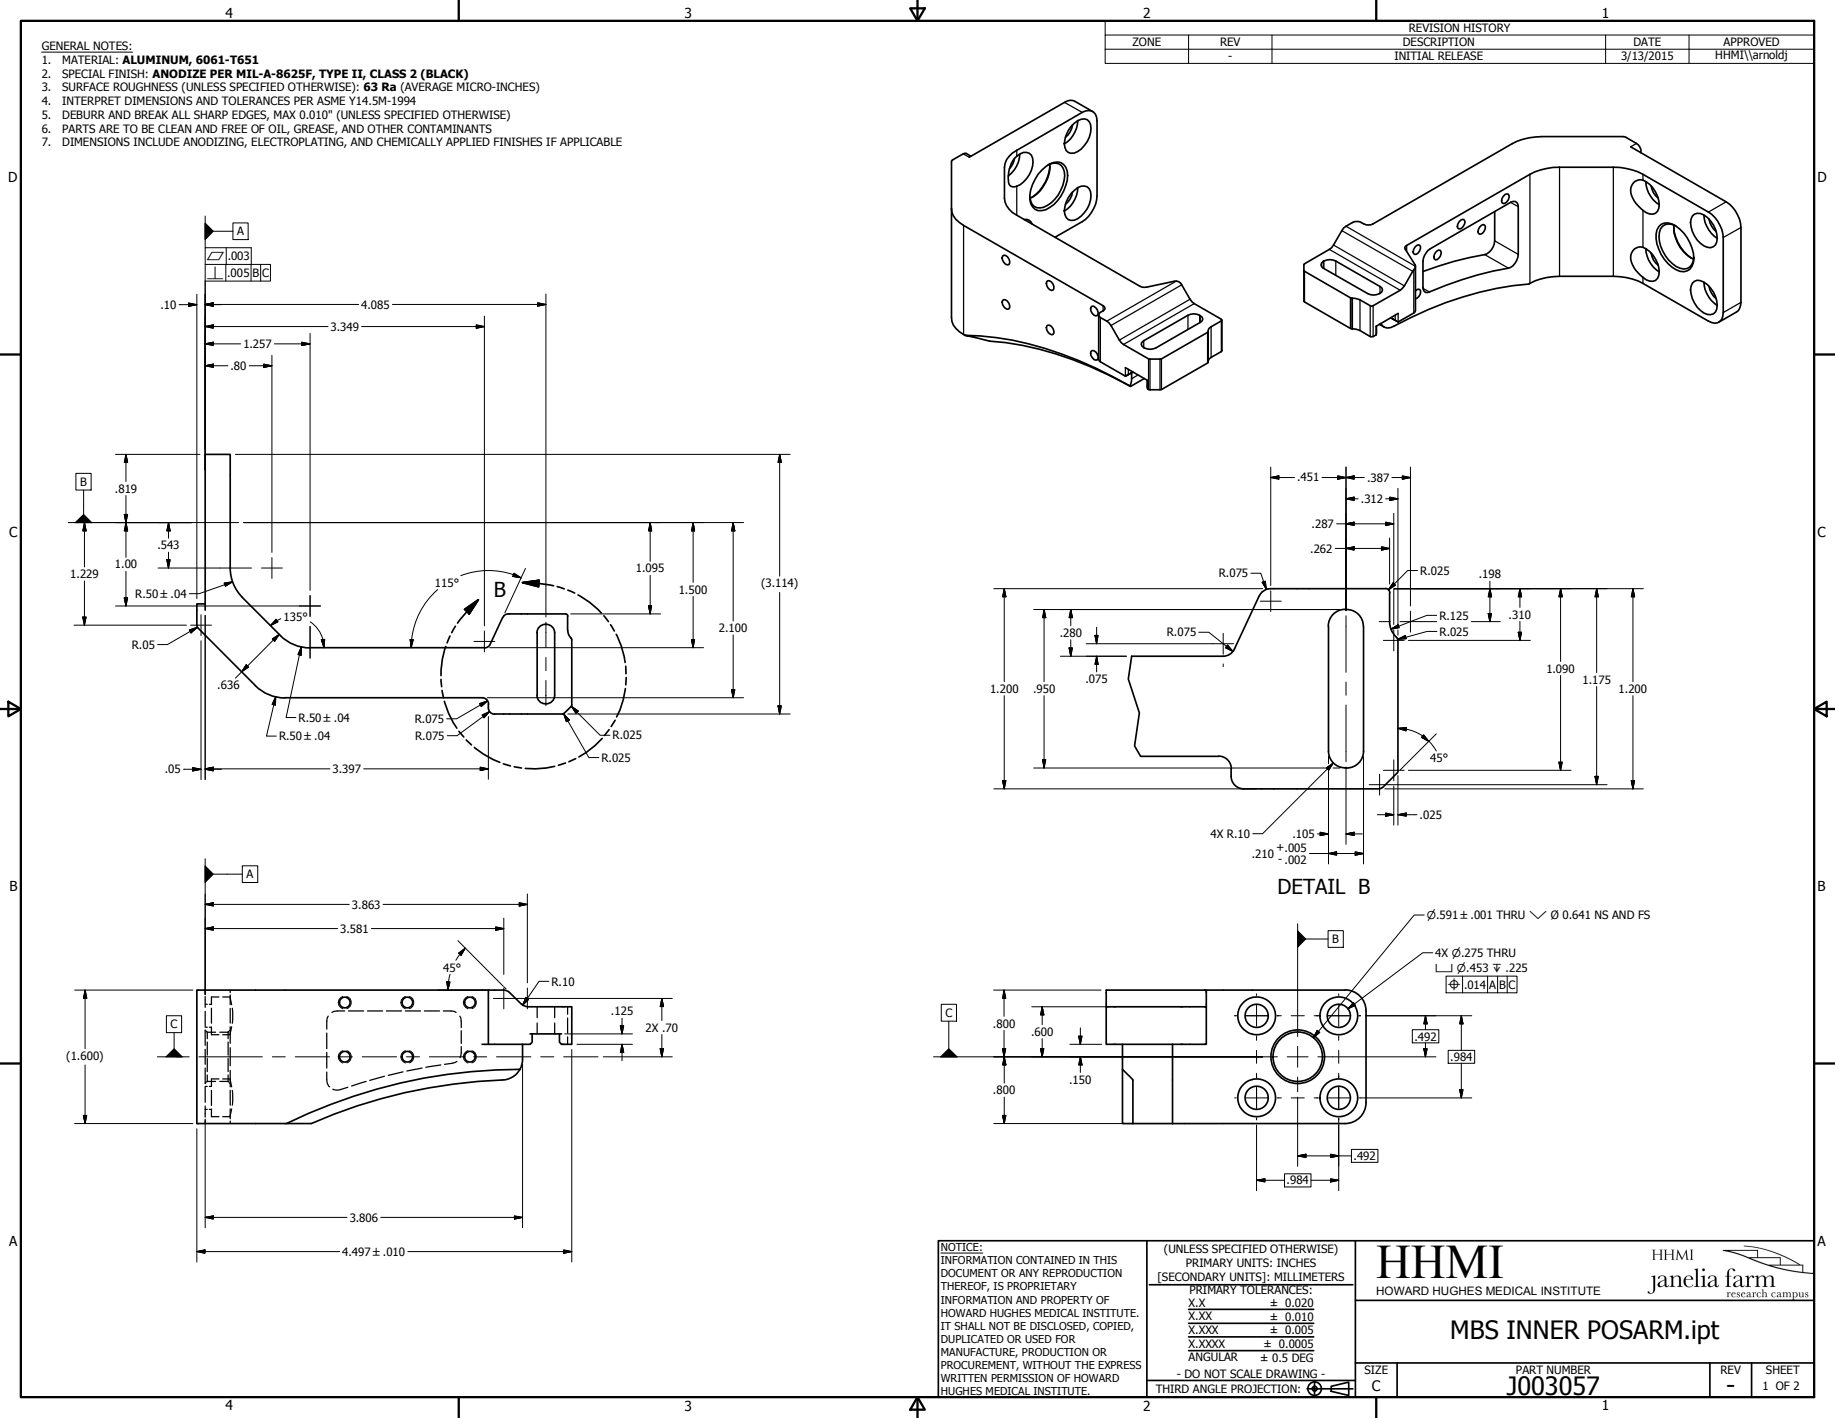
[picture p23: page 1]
DETAIL B; PART NUMBER; HHMI; SIZE; REV; SHEET; 1 OF 2 THIRD ANGLE PROJECTION:; ± 0.020 ± 0.010 ± 0.005 ± 0.0005 ± 0.5 DEG; REVISION HISTORY; ZONE; DESCRIPTION; DATE; APPROVED; INITIAL RELEASE; HHMI\\arnoldj; 4X P.275 THRU X P.453 Z .225

GENERAL NOTES:
1. MATERIAL: ALUMINUM, 6061-T651
2. SPECIAL FINISH: ANODIZE PER MIL-A-8625F, TYPE II, CLASS 2 (BLACK)
3. SURFACE ROUGHNESS (UNLESS SPECIFIED OTHERWISE): 63 Ra (AVERAGE MICRO-INCHES)
4. INTERPRET DIMENSIONS AND TOLERANCES PER ASME Y14.5M-1994
5. DEBURR AND BREAK ALL SHARP EDGES, MAX 0.010" (UNLESS SPECIFIED OTHERWISE)
6. PARTS ARE TO BE CLEAN AND FREE OF OIL, GREASE, AND OTHER CONTAMINANTS
7. DIMENSIONS INCLUDE ANODIZING, ELECTROPLATING, AND CHEMICALLY APPLIED FINISHES IF APPLICABLE

P.591 B.001 THRU Y Ø 0.641 NS AND FS

NOTICE:
INFORMATION CONTAINED IN THIS
DOCUMENT OR ANY REPRODUCTION
THEREOF, IS PROPRIETARY
INFORMATION AND PROPERTY OF
HOWARD HUGHES MEDICAL INSTITUTE.
IT SHALL NOT BE DISCLOSED, COPIED,
DUPLICATED OR USED FOR
MANUFACTURE, PRODUCTION OR
PROCUREMENT, WITHOUT THE EXPRESS
WRITTEN PERMISSION OF HOWARD
HUGHES MEDICAL INSTITUTE.

(UNLESS SPECIFIED OTHERWISE)
PRIMARY UNITS: INCHES
[SECONDARY UNITS]: MILLIMETERS
PRIMARY TOLERANCES:
X.XXX
X.XXXX
ANGULAR
- DO NOT SCALE DRAWING -

HOWARD HUGHES MEDICAL INSTITUTE

MBS INNER POSARM.ipt

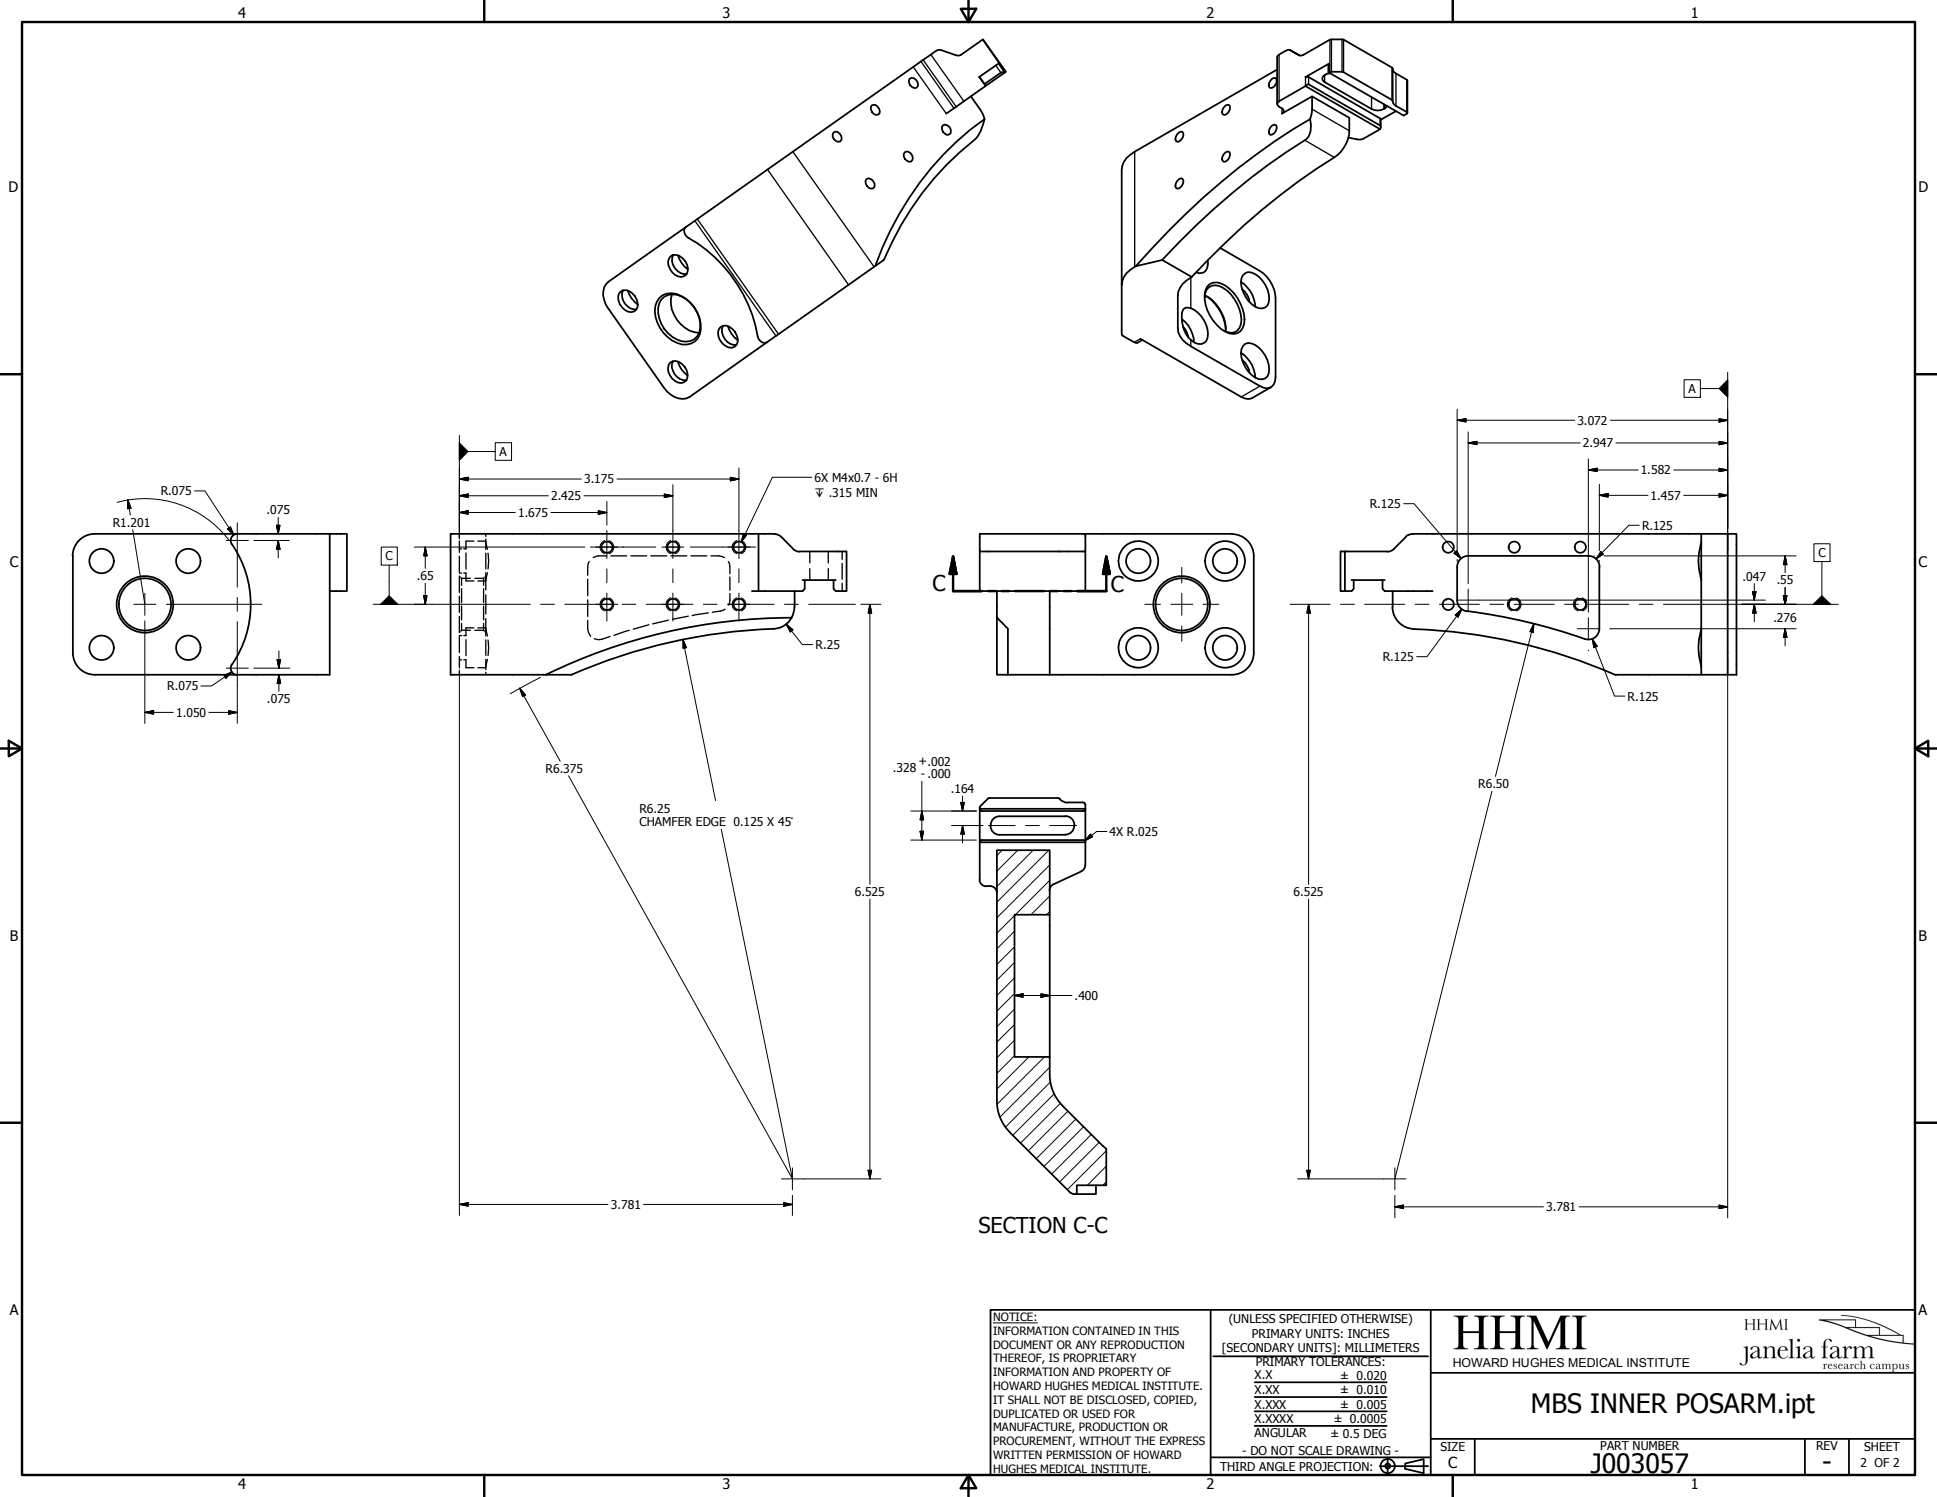
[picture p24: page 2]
SECTION C-C; PART NUMBER; HHMI; SIZE; REV; SHEET; 2 OF 2 THIRD ANGLE PROJECTION:; ± 0.020 ± 0.010 ± 0.005 ± 0.0005 ± 0.5 DEG; R6.25 CHAMFER EDGE 0.125 X 45`; 6X M4x0.7 - 6H Z .315 MIN

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

HOWARD HUGHES MEDICAL INSTITUTE

MBS INNER POSARM.ipt

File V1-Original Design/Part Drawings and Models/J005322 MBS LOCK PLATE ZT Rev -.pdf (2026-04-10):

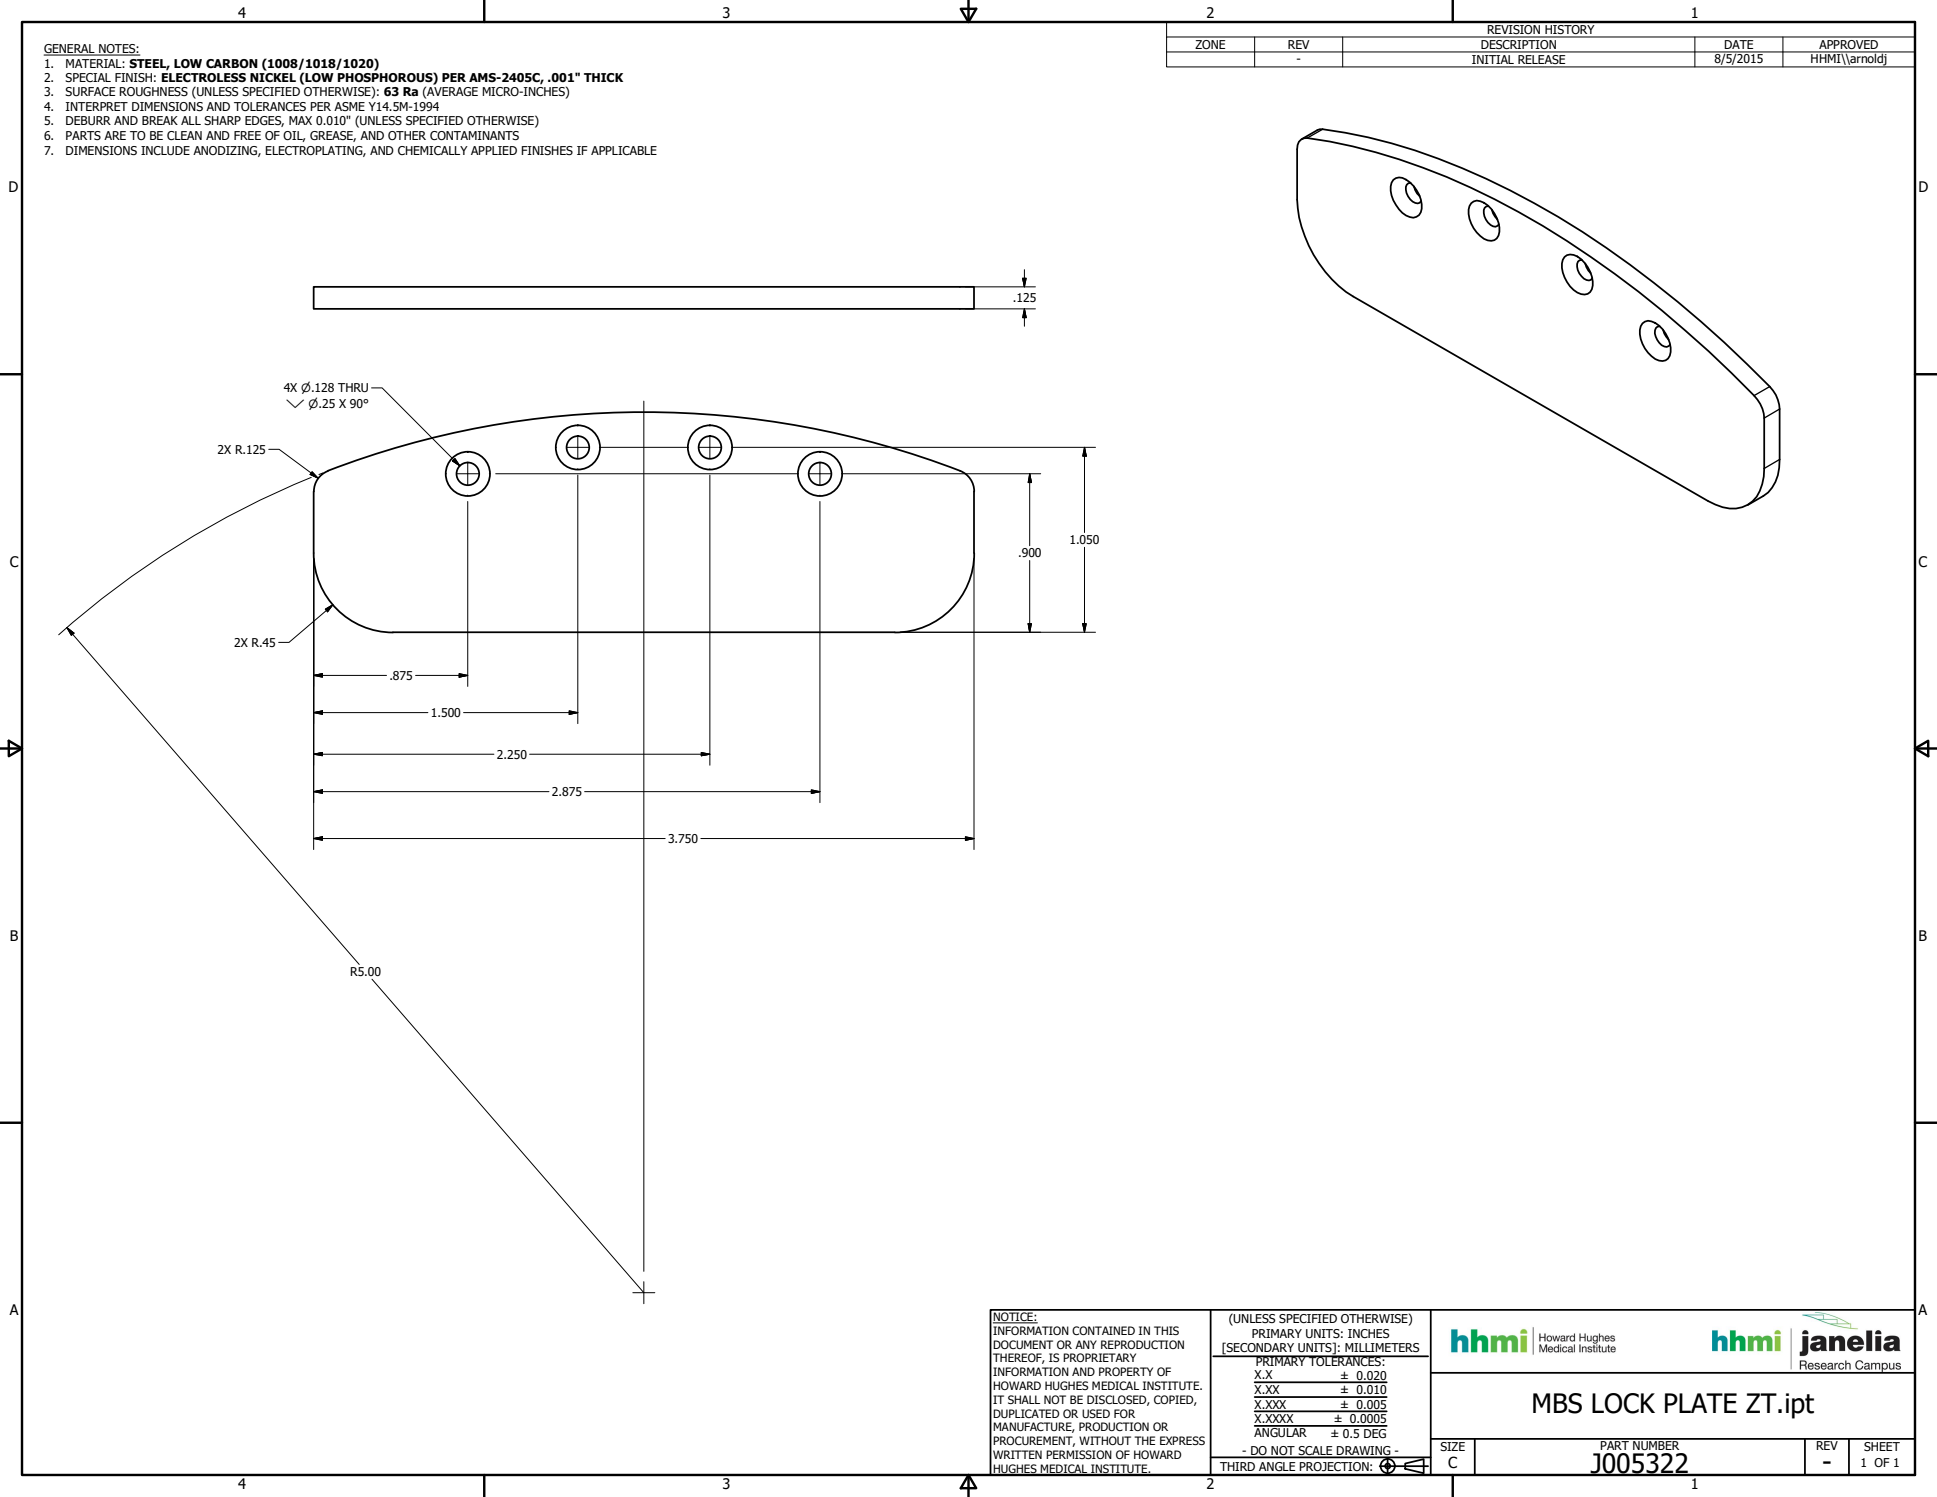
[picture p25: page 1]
PART NUMBER; 1 OF 1 THIRD ANGLE PROJECTION:; ± 0.020 ± 0.010 ± 0.005 ± 0.0005 ± 0.5 DEG; REVISION HISTORY

GENERAL NOTES:
1. MATERIAL: STEEL, LOW CARBON (1008/1018/1020)
2. SPECIAL FINISH: ELECTROLESS NICKEL (LOW PHOSPHOROUS) PER AMS-2405C, .001" THICK
3. SURFACE ROUGHNESS (UNLESS SPECIFIED OTHERWISE): 63 Ra (AVERAGE MICRO-INCHES)
4. INTERPRET DIMENSIONS AND TOLERANCES PER ASME Y14.5M-1994
5. DEBURR AND BREAK ALL SHARP EDGES, MAX 0.010" (UNLESS SPECIFIED OTHERWISE)
6. PARTS ARE TO BE CLEAN AND FREE OF OIL, GREASE, AND OTHER CONTAMINANTS
7. DIMENSIONS INCLUDE ANODIZING, ELECTROPLATING, AND CHEMICALLY APPLIED FINISHES IF APPLICABLE

ZONE | REV | DESCRIPTION | DATE | APPROVED

- | INITIAL RELEASE | 8/5/2015 | HHMI\\arnoldj

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

MBS LOCK PLATE ZT.ipt

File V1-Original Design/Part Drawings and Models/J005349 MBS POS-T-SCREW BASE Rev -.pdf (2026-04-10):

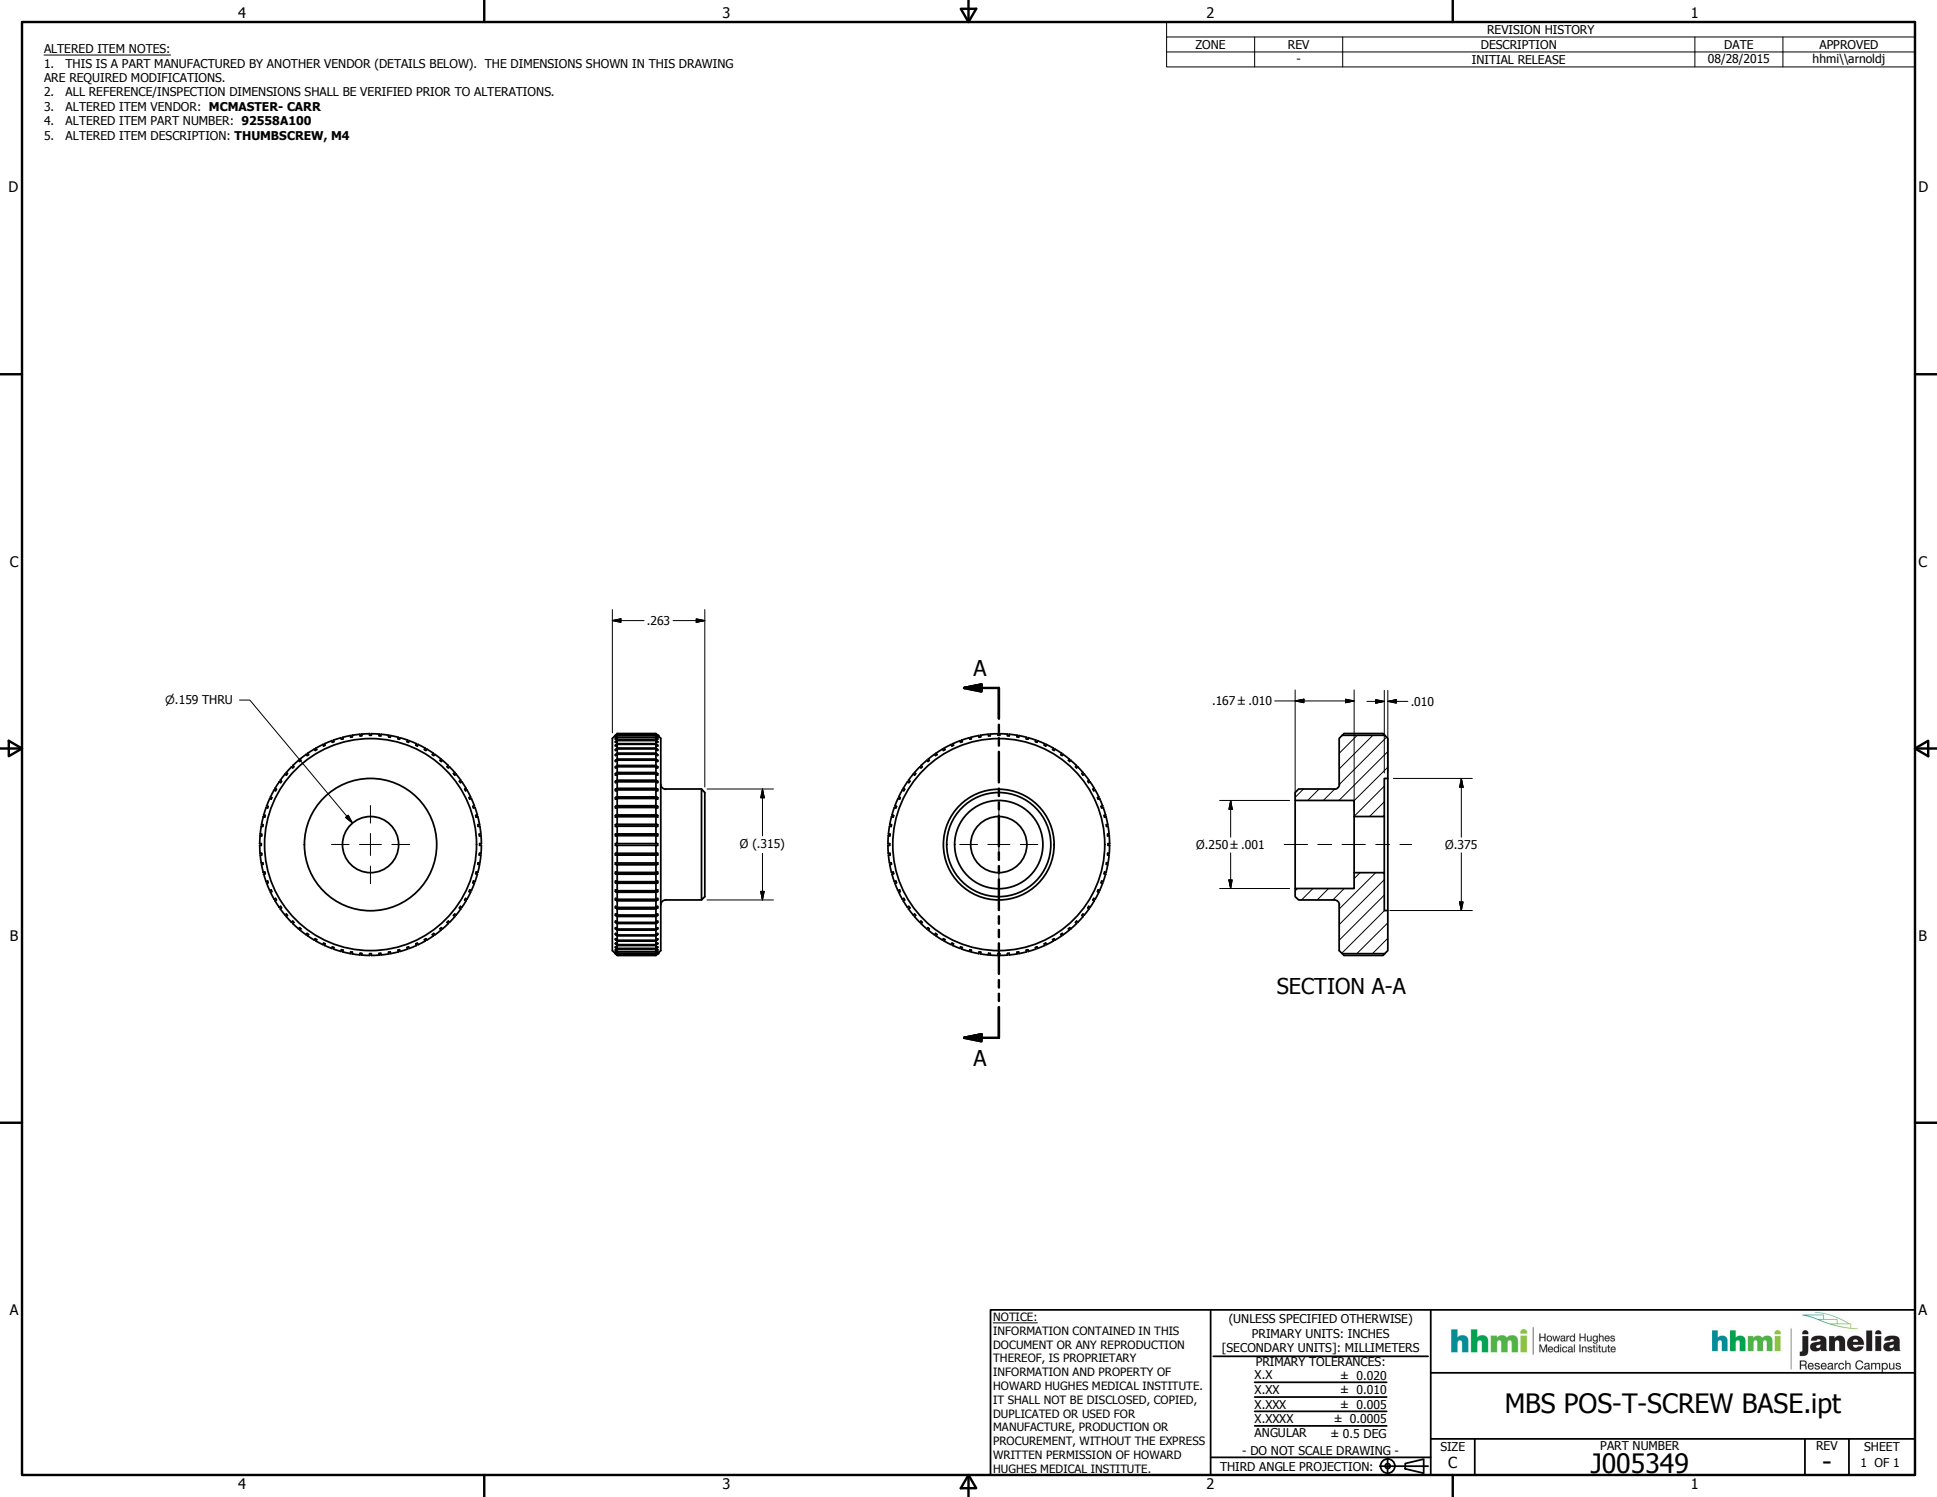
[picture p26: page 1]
SECTION A-A; PART NUMBER; SIZE; REV; SHEET; 1 OF 1 THIRD ANGLE PROJECTION:; ± 0.020 ± 0.010 ± 0.005 ± 0.0005 ± 0.5 DEG; REVISION HISTORY; ZONE; DESCRIPTION; DATE; APPROVED; INITIAL RELEASE; hhmi\\arnoldj; P.159 THRU

ALTERED ITEM NOTES:
1. THIS IS A PART MANUFACTURED BY ANOTHER VENDOR (DETAILS BELOW). THE DIMENSIONS SHOWN IN THIS DRAWING
ARE REQUIRED MODIFICATIONS.
2. ALL REFERENCE/INSPECTION DIMENSIONS SHALL BE VERIFIED PRIOR TO ALTERATIONS.
3. ALTERED ITEM VENDOR: MCMASTER- CARR
4. ALTERED ITEM PART NUMBER: 92558A100
5. ALTERED ITEM DESCRIPTION: THUMBSCREW, M4

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

MBS POS-T-SCREW BASE.ipt
